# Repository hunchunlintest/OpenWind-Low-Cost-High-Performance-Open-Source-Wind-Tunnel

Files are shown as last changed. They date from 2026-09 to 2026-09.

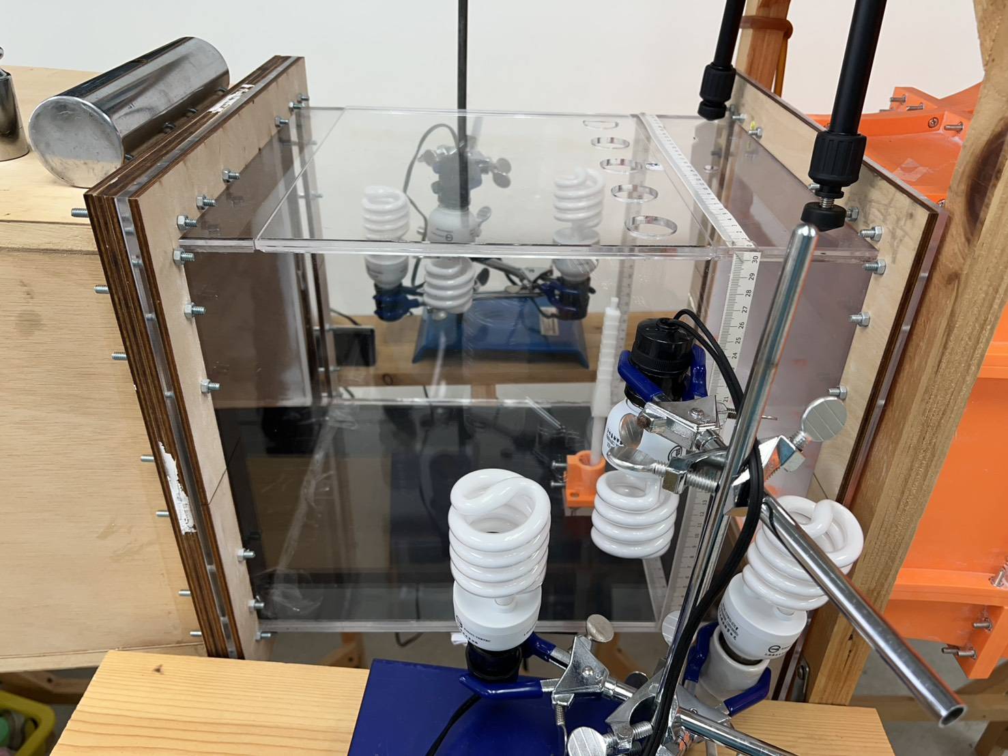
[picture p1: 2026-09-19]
Pictures/Test_Section.jpg

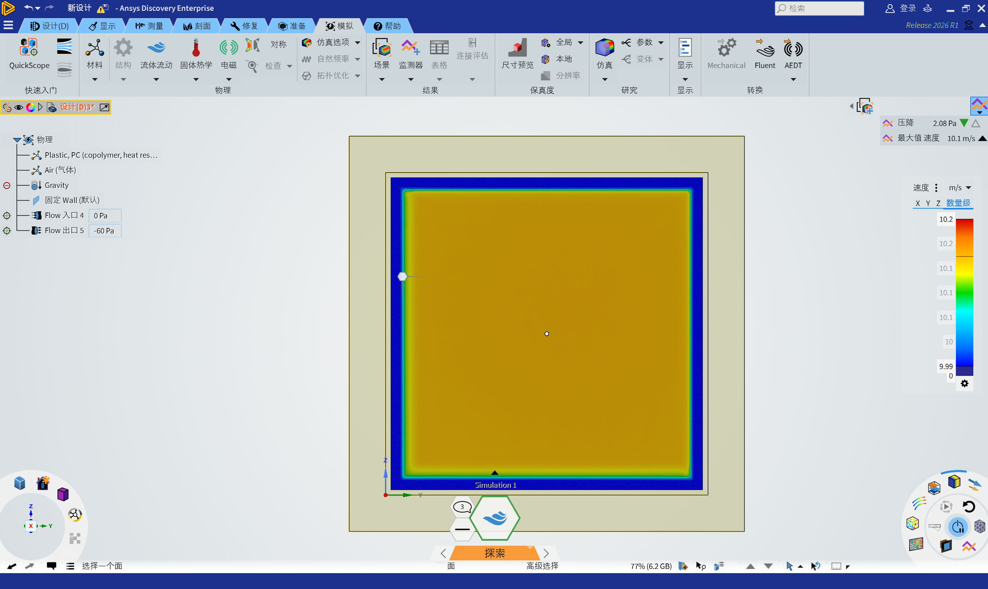
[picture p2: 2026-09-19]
Simulation/Boundary_Test_Section.png

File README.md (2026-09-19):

# OpenWind-Low-Cost-High-Performance-Open-Source-Wind-Tunnel
An open-source, suction-type continuous wind tunnel engineered for low cost and easy assembly. Features a 900 cm² test section, CAD files, Arduino control firmware, and assembly guides. Optimized via ANSYS Discovery to deliver precise PWM speed control (up to 10 m/s) with high flow uniformity and low turbulence (T.I. < 1.6%).

---

> ⚠️ **Important Notes:**
> * Ensure your room has sufficient space to accommodate the assembled wind tunnel structure and proper airflow!
> * You may need to modify the CAD models to fit your specific 3D printer dimensions or hardware components.
> * You will need to design a custom support frame based on your specific environment and perform system calibration prior to testing.
> * If you need help, please contact me. Email: edisonlin2009@proton.me

---

## 📂 Repository Structure (Directory Contents)

| Directory / File | Description |
| :--- | :--- |
| **`Contraction Cone/`** | Specifications and post-processing guide for the 3D-printed contraction section. |
| **`Diffuser Section/`** | Dimensions and setup for the wooden expansion duct for pressure recovery. |
| **`Gallery/`** | High-resolution photographs showcasing the physical assembly and individual modules. |
| **`Power Section/`** | Arduino PWM control firmware (`.ino`), wiring guidelines, and fan array setup. |
| **`Simulation/`** | ANSYS Discovery CFD analysis visualizations (velocity contours, streamlines). |
| **`Straightening Section/`** | DIY instructions for the drinking straw honeycomb array and wire mesh. |
| **`Test Section/`** | Specifications for the transparent acrylic observation area and sensor ports. |
| **`PRICE_LIST.md`** | Detailed itemized Bill of Materials (BOM) with estimated USD costs. |
| **`LICENSE`** | MIT License open-source legal information. |

---

## 🛠️ Hardware & Bill of Materials (BOM)

### 1. Wind Tunnel Structure Modules
*   **Flow Straightener Section (Honeycomb & Mesh)**:
    *   Plastic straws (1 cm diameter, aligned in a honeycomb pattern)
    *   Stainless steel wire mesh
*   **Contraction Section (Contraction Cone)**:
    *   3D printed components (PLA)
    *   Wall putty / spackle
*   **Test Section (Observation Section)**:
    *   Acrylic plates
    *   Pre-drilled ports for Pitot tube and smoke generator injection
*   **Diffuser Section**:
    *   Tapered enclosure panels (Length: 120 cm)

### 2. Power & Control System (You can choose your own!)
*   **Fans**: Snow Fan YY20060H24 × 4 
*   **Microcontroller**: Arduino UNO × 1
*   **Motor Driver**: APO-L3 PWM Controller × 1
*   **Power Supply**: MEAN WELL LRS-350-24 (24V) × 1

### 3. Optional Measurement & Testing Gear
*   Pitot tube anemometer (e.g., PASCO ME-2221)
*   Smoke generator (for flow visualization)
*   High-speed camera (e.g., XIMEA XIQ)

---

## 💻 Software & Files

*   **Autodesk Fusion 360**: 3D structural model source files (`.f3d`) and printable files (`.stl`).
*   **Arduino IDE**: Firmware for fan speed control via PWM (`.ino`).

---

## 📊 Performance Specs

Replicated and measured experimentally, this setup achieves the following specifications:

*   **Test Section Cross-Section**: 900 cm² (30 cm × 30 cm)
*   **Maximum Wind Speed**: 10 m/s
*   **Flow Field Uniformity**: Post-sanding treatment of the contraction cone reduces test section Turbulence Intensity (T.I.) to below **1.6%**.
*   **Control Linearity**: High linear relationship ($R^2 = 0.9996$) between Arduino PWM duty cycle and average test section wind speed.
*   **Operating Stability**: Continuous 60-minute test shows 5-minute average wind speed fluctuations staying within a **$\pm 5\%$** error margin.

---

## 🚀 Getting Started

1. **Download CAD Files**: Clone this repository and navigate to the CAD directory to get the `.stl` files.
2. **3D Printing & Post-Processing**: Print the contraction cone parts and assemble them. **Apply wall putty to the interior walls and sand repeatedly until smooth** to ensure low turbulence intensity.
3. **Assemble Main Structure**: Connect the components in sequence: Straightener $\rightarrow$ Contraction Cone $\rightarrow$ Acrylic Test Section $\rightarrow$ Diffuser $\rightarrow$ Fan Power Section. Seal all joining edges to prevent air leaks. Secure the entire assembly onto your custom-built support frame.
4. **Wiring & Firmware Flashing**:
   * Connect the Arduino UNO, APO-L3 PWM driver, LRS-350-24 power supply, and Snow Fans according to the provided circuit diagram.
   * Open Arduino IDE and upload the control script to the Arduino UNO.
5. **Operation & Calibration**: Power on the system, send PWM signals to control fan speed, and use your measurement tools (e.g., Pitot tube) to calibrate the wind speed against the PWM output for your specific build environment.

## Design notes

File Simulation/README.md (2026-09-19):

# 🌪️ Simulation & CFD Analysis

This directory contains Computational Fluid Dynamics (CFD) simulation results used to verify and optimize the aerodynamic performance of the OpenWind modular wind tunnel.
## 💻 Simulation Software
The modeling, simulation, and visualization were conducted using **ANSYS Discovery**, leveraging its rapid simulation capabilities to iterate on the contraction cone and diffuser designs.

## 📊 Key Results (Visualizations)
Below are two key visualization results from our ANSYS Discovery analysis.

<!-- IMPORTANT: Please rename the image filenames in this directory to match your actual uploaded file names and replace them in the paths below (e.g., replace './image_7.png' with './sim_full_streamlines.png'). -->

### 1. Wind Tunnel Flow Path Streamlines (Overview)

*   **Description**: This full wind tunnel overview displays flow path streamlines colored by velocity magnitude. It demonstrates:
    *   Efficient flow acceleration through the 3D-printed contraction cone.
    *   Smooth flow development into the test section, validating the overall modular design.
    *   Effective velocity recovery within the diffuser section before exhaust.
*   **Result**: The simulation indicates a smooth velocity increase from the straightener to the test section.

### 2. Test Section Velocity Contour (Cross-Section)

*   **Description**: This is a cross-sectional velocity contour plot taken directly from the acrylic test section. It is designed to verify:
    *   High flow uniformity across the 900 cm² (30 cm x 30 cm) working area.
    *   Minimal turbulence and low velocity boundary layers at the square edges.
*   **Result**: The core region shows excellent velocity uniformity, with a maximum velocity of approximately **$10.2\text{ m/s}$**, validating the design's ability to achieve the target maximum wind speed.

---

## 📁 Full Simulation Files Request

> **⚠️ Notice regarding raw files:**
> Due to GitHub's file size limitations, the original complete ANSYS Discovery simulation files (project databases, full result sets, and volumetric data) **exceed the 25MB upload limit** and are not hosted directly in this repository.

If you require the original simulation data for academic verification, joint research, or your own modifications, please feel free to contact me directly:

📧 **Email**: [edisonlin2009@proton.me](mailto:edisonlin2009@proton.me)

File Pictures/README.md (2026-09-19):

#Pictures

This gallery contains high-resolution photographs showcasing the physical assembly, structural components, measurement setup, and power system of the OpenWind modular wind tunnel.

---

## 🖼️ Modular Overview & Components

| Image | Component / Module | Description |
| :---: | :--- | :--- |
| **`Full_Windtunnel.jpg`** | **Full Assembly ** | Side view of the complete open-source modular wind tunnel system mounted on a wooden framework, showing the flow progression from intake to exhaust. |
| **`Straighten_Section.jpg`** | **Straightening Section ** | Front view of the intake module featuring the wooden casing, $10\text{ mm}$ drinking straw honeycomb array, fine wire mesh screen, and pressure sensing probe. |
| **`Convergent_Section.jpg`** | **Contraction Cone ** | Side profile of the 3D-printed orange contraction cone designed to accelerate air into the test section while minimizing turbulence. |
| **`Test_Section.jpg`** | **Test Section ** | Transparent acrylic working section equipped with lighting fixtures, measurement rulers, and test model mounting rigs. |
| **`Diffusion_Section.jpg`** | **Diffuser Section ** | Heavy-duty wooden expansion duct ($120\text{ cm}$ length, $2\text{ cm}$ wall thickness) designed for pressure recovery downstream of the test section. |
| **`Power_Section.jpg`** | **Power Section & Control ** | Rear exhaust module housing the $2 \times 2$ array of $20\text{ cm} \times 20\text{ cm}$ fans, connected to the PWM microcontroller control setup and data acquisition workstation. |

---

## 🛠️ Usage in Documentation

You can reference these images in your respective sub-module `README.md` files using standard Markdown syntax:

```markdown
![Straightening Section](./Straighten_Section.jpg)

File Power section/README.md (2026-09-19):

# Power Section

This directory contains the specification, wiring guidelines, and safety instructions for the Power Section of the open-source wind tunnel.

The power section serves as the primary suction power source, drawing air through the entire tunnel system using a multi-fan array with integrated power supply and PWM speed control electronics.

---

## 📂 Directory Contents

| File Name | Format | Description |
| :--- | :---: | :--- |
| **`Power_Section.ino`** | Arduino (`.ino`) | Embedded C++ sample code for microcontroller PWM fan speed control, timer setup, and dynamic duty cycle mapping. |

---

## 📐 Hardware Specifications & Configuration

* **Fan Matrix**: $2 \times 2$ grid array (Total of 4 high-performance exhaust fans)
* **Fan Frame Dimensions**: $20\text{ cm} \times 20\text{ cm}$ per fan (Total cross-section area fits the outlet of the diffuser)
* **Drive Type**: Pull-through (suction) configuration mounted at the downstream exit of the diffuser
* **Operating Voltage**: 12V / 24V DC (depending on selected fan model)

---

## ⚡ Electrical & Control System

The electrical system consists of three core components: Power Supply Unit (PSU), Speed Controller, and Safety Circuitry.

### 1. Power Supply Unit (PSU)
* **Voltage Rating**: Matches fan requirements (typically 12V or 24V DC).
* **Current Capacity**: Ensure the PSU rated current ($A$) exceeds the total combined peak current draw of all 4 fans by at least **20–30%** (Safety Margin).

### 2. Speed Control (PWM)
* **Control Signal**: 4-wire PWM (Pulse Width Modulation) signal generator or microcontroller (e.g., Arduino / ESP32) for precise wind speed tuning.
* **Synchronization**: All 4 fans must receive identical PWM signal duty cycles to maintain uniform suction pressure across the exit boundary.

### 3. Wiring Guidelines
* **Bus Wiring**: Wire power in parallel across all 4 fans using appropriate gauge wire (e.g., 16–18 AWG) to prevent voltage drops.
* **Common Ground**: Ensure a common ground (GND) is shared between the PWM controller and the main power supply.

---

## 🛠️ Assembly & Safety Guidelines

1. **Vibration Isolation**:
   * Mount rubber gaskets or silicone dampeners between the fan housing and the diffuser mounting flange to minimize structural vibration and resonance.
2. **Safety Grilles / Finger Guards**:
   * **Mandatory**: Install protective wire mesh or fan guards on the rear exhaust face to prevent accidental contact with spinning blades.
3. **Thermal Management**:
   * Enclose all control electronics and terminal blocks inside a ventilated, flame-retardant junction box.

---

## ✏️ Customization & Modifications

> ⚠️ **Important Note:** You can adapt this power section for different fan dimensions or higher-voltage brushless motors (EDF) by adjusting the power supply capacity and speed controller specifications accordingly.

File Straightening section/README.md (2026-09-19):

# Straightening Section

This directory contains the CAD models, manufacturing specs, and assembly instructions for the Straightening Section located at the wind tunnel inlet.

The straightening section stabilizes incoming ambient air by eliminating large-scale eddies, swirl, and non-uniform lateral velocities before the air enters the contraction cone.

Notice: The CAD in this File is without the pipes.

---

## 📐 Dimensional Specifications

* **Outer Frame Cross-Section**: $60\text{ cm} \times 60\text{ cm}$ (Matches the inlet opening of the contraction cone)
* **Honeycomb Cell Diameter**: $10\text{ mm}$ (Array constructed using densely packed drinking straws)
* **Honeycomb Depth**: $13\text{ cm}$
* **Damping Mesh / Screen**: Fine stainless steel wire mesh placed upstream and downstream of the straw honeycomb block
* **Outer Frame Material**: Custom wooden enclosure framing

---

## 📂 Directory Contents

| File Name | Format | Description |
| :--- | :---: | :--- |
| **`Straightening_Section.pdf`** | PDF | Technical engineering drawing showing dimensions of the wooden frame layout. |
| **`Straightening_Section.step`** | STEP (`.step`) | 3D CAD model of the outer wooden housing and assembly structure. |

---

## 🛠️ Material & DIY Manufacturing Guidelines

The straightening section is constructed using accessible low-cost materials:

1. **Wooden Outer Frame**:
   * Build a robust $60\text{ cm} \times 60\text{ cm}$ inner-dimension box (with a depth of at least $13\text{ cm}$) using wooden panels to serve as the structural casing.
2. **Drinking Straw Honeycomb Core**:
   * **Material**: Standard plastic drinking straws ($10\text{ mm}$ diameter, cut to $13\text{ cm}$ lengths).
   * **Assembly**: Bundle and align straws tightly in a parallel hexagonal pattern inside the wooden frame until the entire $60\text{ cm} \times 60\text{ cm}$ cross-section is completely filled. Secure the bundle edges with spray adhesive or side clamping panels.
3. **Stainless Steel Screen Mesh**:
   * Fasten fine stainless steel wire mesh onto both the front (intake) and rear (outlet) faces of the wooden frame to secure the straw matrix and further reduce flow fluctuations.

---

## ✏️ Customization & Modifications

> ⚠️ **Important Note:** You can adjust the wooden panel thickness or overall frame depth to match alternative straw lengths or custom mounting flanges on the downstream contraction cone.

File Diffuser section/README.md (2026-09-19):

# Diffuser Section
This directory contains the CAD models, dimensional specifications, and assembly instructions for the Diffuser Section of the open-source wind tunnel.

The diffuser is a tapered expansion duct designed to gradually decelerate high-velocity airflow exiting the test section, reducing static pressure losses and preventing downstream wake instability.

---

## 📐 Dimensional Specifications

* **Total Length**: $120\text{ cm}$
* **Inlet Cross-Section**: $30\text{ cm} \times 30\text{ cm}$ (Matches the acrylic test section output)
* **Outlet Cross-Section**: Tapered expansion to fit the fan drive array housing
* **Wall Thickness**: $2\text{ cm}$ ($20\text{ mm}$) board/panel material construction
* **Duct Profile**: Linear geometric expansion optimized for stable pressure recovery

---

## 📂 Directory Contents

| File Name | Format | Description |
| :--- | :---: | :--- |
| **`擴散器部分.pdf`** | PDF | Engineering technical drawing detailing overall dimensions. |
| **`擴散器部分.步驟`** | STEP (`.step`) | Standard 3D CAD exchange file for CAD editing software import. |

---

## 🛠️ Fabrication & Assembly Guidelines

Depending on your available tools and workspace, the 120 cm long diffuser can be built using sheet materials or 3D printed modular sections:

1. **Sheet Material Construction (Recommended)**:
   * **Materials**: $2\text{ cm}$ thick wood/MDF boards, acrylic panels, or dense plastic sheets.
   * **Cutting**: Cut 4 trapezoidal panels (taking the $2\text{ cm}$ material thickness into account for edge overlaps).
2. **Air Tightness (Critical)**:
   * Apply silicone sealant or foam gasket tape along all internal longitudinal seams.
   * Air leaks in the diffuser section degrade fan suction efficiency and introduce flow turbulence.
3. **Fan Array Attachment**:
   * Mount the 4× Snow Fan array securely at the outlet flange. Ensure vibration-dampening rubber pads are placed between the diffuser housing and fan frame.

---

## ✏️ Customization & Modifications

> ⚠️ **Important Note:** If you are using different fan models, alternative board thicknesses, or a custom power array, you may need to adjust the outlet cross-section dimensions and panel edge joint geometries in the CAD source file (`.f3d`) prior to fabrication.

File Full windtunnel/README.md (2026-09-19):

# Full Wind Tunnel

This directory contains the complete assembly CAD models, render images, and overall dimensional drawings for the entire open-source wind tunnel system.

It is designed to give users a clear high-level view of the full structure, component layout, and physical space requirements before manufacturing and assembly.

##Some of the Detail is not in the CAD in this File!

---

## 📐 Overall Dimensions & Workspace Requirements

Please review these overall spatial specs to ensure your workspace or lab environment can accommodate the fully assembled unit:

* **Total Length**: Approx. $2.5\text{ m} - 3.0\text{ m}$ (including Honeycomb, Contraction Cone, Test Section, Diffuser, and Fan Array).
* **Cross-Sectional Height & Width**: Max outer dimension approx. $60\text{ cm} \times 60\text{ cm}$ at the contraction/diffuser ends.
* **Test Section Working Area**: $30\text{ cm} \times 30\text{ cm} \times 40\text{ cm}$.

> ⚠️ **Workspace Clearance Notice:** Ensure a minimum clearance of **1 meter** around both the front air intake (honeycomb) and the rear exhaust (fans) to prevent flow restriction or wall interference.

---

## 🛠️ Assembly Sequence Overview

The wind tunnel modules should be connected in the following order along the flow path:

1. **Honeycomb / Flow Straightener** (Inlet)
2. **Contraction Cone** (Flow Acceleration)
3. **Acrylic Test Section** (Observation & Measurement)
4. **Diffuser** (Flow Expansion)
5. **Fan Drive Array & Housing** (Power & Exhaust)

---

## ✏️ Customization & Adjustments

> ⚠️ **Important Note:** You can open the source assembly file in Autodesk Fusion 360 to measure specific clearance dimensions, export custom sections, or modify adapter flanges to fit alternative components.

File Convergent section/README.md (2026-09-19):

# Contraction Section

This directory contains the CAD models, 3D printing files, and post-processing instructions for the contraction cone section of the open-source wind tunnel.

The contraction cone is a critical component designed to accelerate incoming airflow and significantly improve flow uniformity while minimizing turbulence intensity before entering the test section.

---

## 📂 Directory Contents & 3D Printing Quantities

The contraction cone is split into 8 different zones and sub-blocks to fit standard desktop 3D printer build volumes. 

> ⚠️ **Note on File Naming:** The number in parentheses `(xN)` inside the filename indicates the **required quantity to print** for that specific component.

| File Name | Required Quantity | Description |
| :--- | :---: | :--- |
| **`WINDZONE1-1(x4).stl`** | 4 | Contraction Cone Zone 1 - Part 1 |
| **`WINDZONE1-2(x8).stl`** | 8 | Contraction Cone Zone 1 - Part 2 |
| **`WINDZONE2-1(x4).stl`** | 4 | Contraction Cone Zone 2 - Part 1 |
| **`WINDZONE2-2(x8).stl`** | 8 | Contraction Cone Zone 2 - Part 2 |
| **`WINDZONE3-1(x4).stl`** | 4 | Contraction Cone Zone 3 - Part 1 |
| **`WINDZONE3-2(x4).stl`** | 4 | Contraction Cone Zone 3 - Part 2 |
| **`WINDZONE4-1(x4).stl`** | 4 | Contraction Cone Zone 4 - Part 1 |
| **`WINDZONE4-2(x4).stl`** | 4 | Contraction Cone Zone 4 - Part 2 |

* **Total Printed Parts**: 40 individual pieces.

---

## 🛠️ Manufacturing & Post-Processing (Crucial Step)

The interior surface quality of the contraction cone directly impacts the turbulence intensity (T.I.) in the test section. To achieve a T.I. below **1.6%**, follow these post-processing steps:

1. **3D Printing**:
   * **Material**: PLA (or ABS/PETG).
   * **Infill**: 15–20% is sufficient.
     
2. **Assembly**:
   * Assemble the printed sub-blocks using M8 screw.
   * Ensure structural alignment along the interior contraction profile.
     
3. **Surface Smoothing (Required)**:
   * **Spackle / Wall Putty**: Apply wall putty or filler evenly across all interior seams and layer lines.
   * **Sanding**: Repeatedly sand the interior surface using progressively finer sandpaper (e.g., 200 $\rightarrow$ 400 $\rightarrow$ 800 grit) until completely smooth.
   * **Finishing**: Apply a coat of primer or clear spray paint to seal the surface.

---

## ✏️ Customization & Modifications

> ⚠️ **Important Note:** Depending on your 3D printer's build volume or specific structural needs, you may need to modify the CAD models to adjust the section splitting or wall thickness before printing.

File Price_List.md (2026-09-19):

# 🏷️ Price List & Cost Breakdown

> ⚠️ **Disclaimer
> The prices listed below are **rough estimates** based on average online pricing for standard materials. **Actual costs will vary depending on your local material prices, shipping fees, inflation, and any additional manufacturing/processing costs** (e.g., custom laser cutting for acrylic or professional 3D printing services if not done in-house).

This document provides a detailed estimation of the material costs required to build the OpenWind modular wind tunnel in USD.

## 🛒 Estimated Cost Table

| Module | Item | Specifications | Qty | Unit Price (USD) | Total (USD) |
| :--- | :--- | :--- | :---: | :---: | :---: |
| **General** | Wooden Panels | 2 cm thickness (for Diffuser & Frames) | 1 set | $45.00 | $45.00 |
| **General** | Fasteners | M4/M5 screws, metal L-brackets | 1 set | $10.00 | $10.00 |
| **Straightening** | Drinking Straws | 10 mm diameter, bulk (cut to 13 cm) | 1 set | $20.00 | $20.00 |
| **Straightening** | Wire Mesh | Fine stainless steel mesh (60 x 60 cm) | 2 pcs | $8.00 | $16.00 |
| **Contraction** | 3D Filament | PLA or PETG (approx. 2-3 spools) | 3 kg | $18.00 | $54.00 |
| **Test Section** | Clear Acrylic | 30 x 30 x 40 cm working area | 1 set | $35.00 | $35.00 |
| **Power Section** | Exhaust Fans | 20 x 20 cm, 12V or 24V DC | 4 pcs | $22.00 | $88.00 |
| **Power Section** | Power Supply (PSU)| Matched to fans (20-30% safety margin)| 1 set | $35.00 | $35.00 |
| **Power Section** | Microcontroller | Arduino Uno / Nano or ESP32 | 1 pc | $8.00 | $8.00 |
| **Power Section** | Electronics | 10k Potentiometer, 16-18 AWG wires | 1 set | $5.00 | $5.00 |
| **Power Section** | Fan Guards | 20 x 20 cm metal safety grills | 4 pcs | $3.50 | $14.00 |
| **Total Estimation**| | | | | **~$330.00** |

---

## 💡 Cost Optimization Notes

* **Cost-Efficiency**: Traditional commercial wind tunnels can cost thousands to tens of thousands of dollars. By utilizing open-source 3D printed components, a DIY drinking straw honeycomb array, and standard industrial computer fans, the overall hardware cost of this project is successfully compressed to under **$350 USD**.
* **Price Variation & Processing**: As mentioned above, actual costs will heavily depend on regional availability. If you require third-party processing (such as CNC machining for wood panels or laser cutting for the acrylic test section), please factor those service fees into your budget.
* **Alternative Materials**: Builders can further reduce costs by using repurposed wood, recycled acrylic sheets, or salvaging power supplies from old desktop computers, depending on local resources.

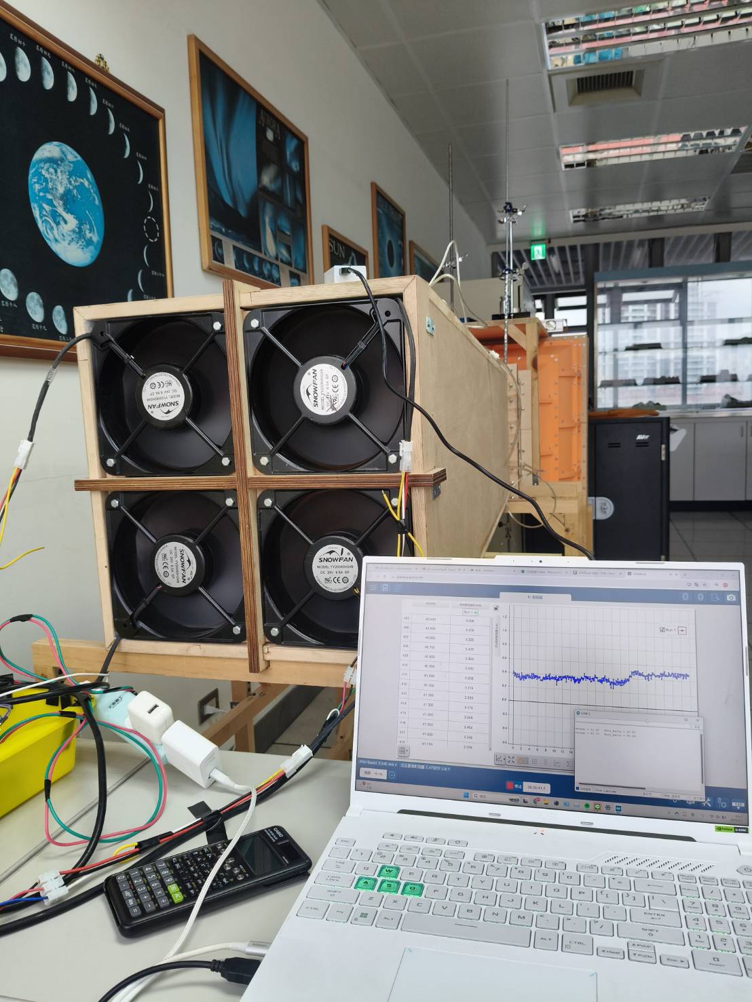
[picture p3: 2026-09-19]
Pictures/Power_Section.jpg

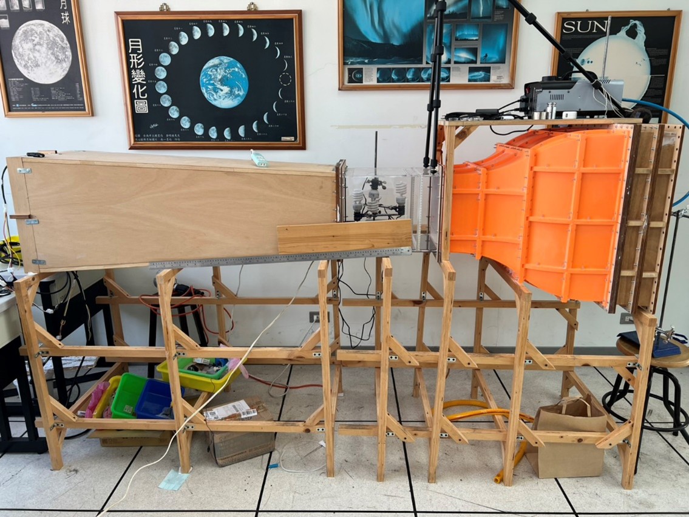
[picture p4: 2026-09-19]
Pictures/Full_Windtunnel.jpg

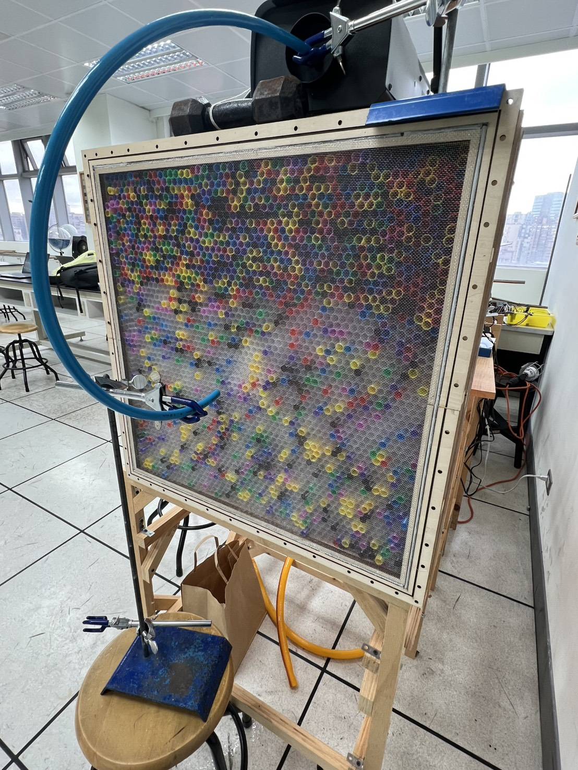
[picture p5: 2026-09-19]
Pictures/Straighten_Section.jpg

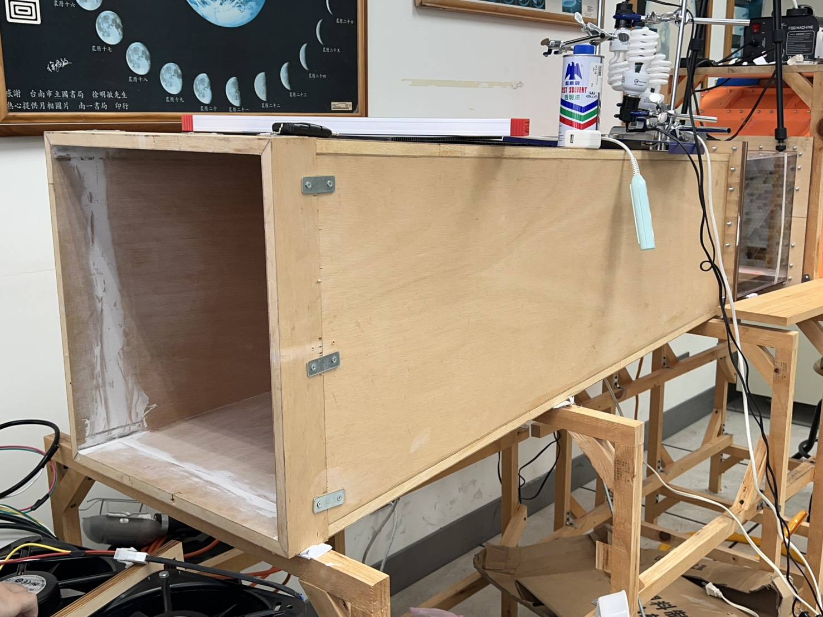
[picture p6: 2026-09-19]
Pictures/Diffusion_Section.jpg

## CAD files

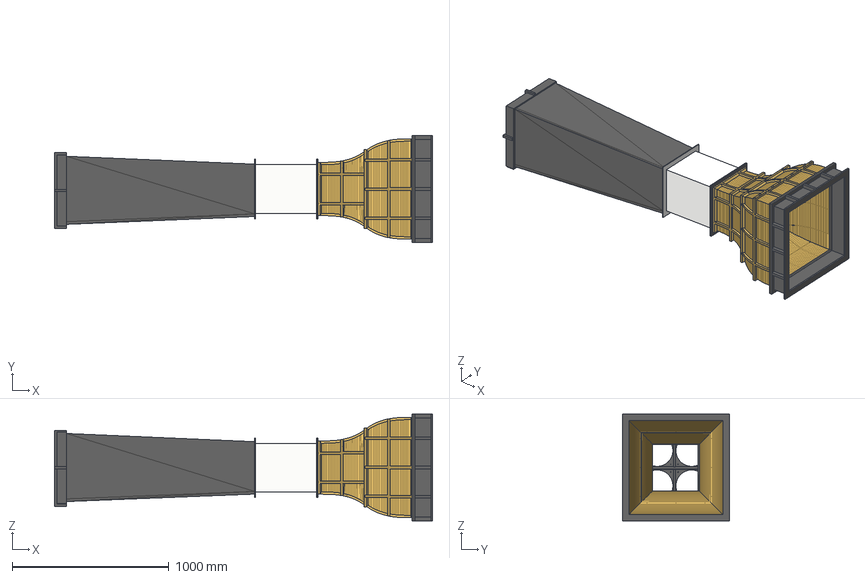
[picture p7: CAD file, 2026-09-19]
Full windtunnel/Full_Windtunnel.step
2410.2 x 680.0 x 680.0 mm
OuterShell x 4
TEST SECTION

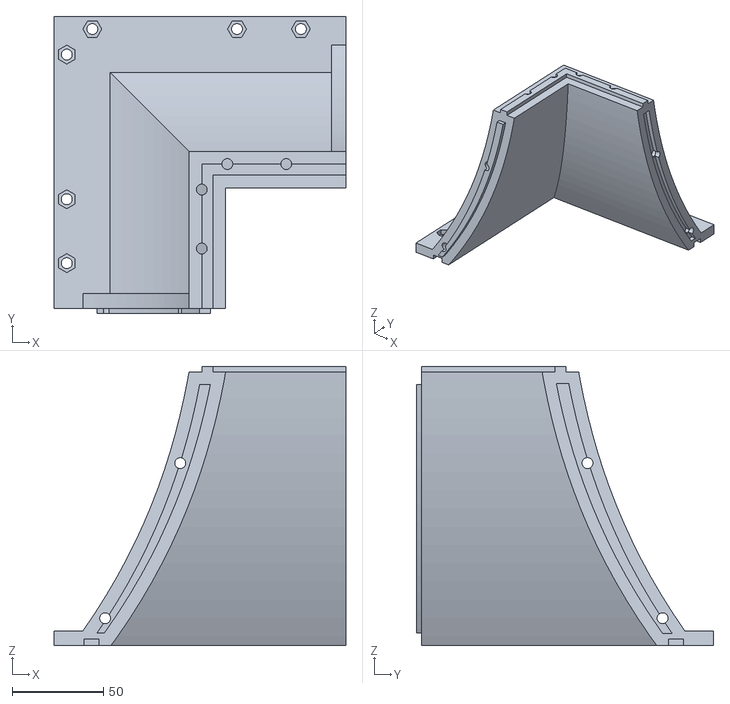
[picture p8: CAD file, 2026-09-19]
Convergent section/WINDZONE3-1(x4).stl
160.0 x 163.0 x 153.0

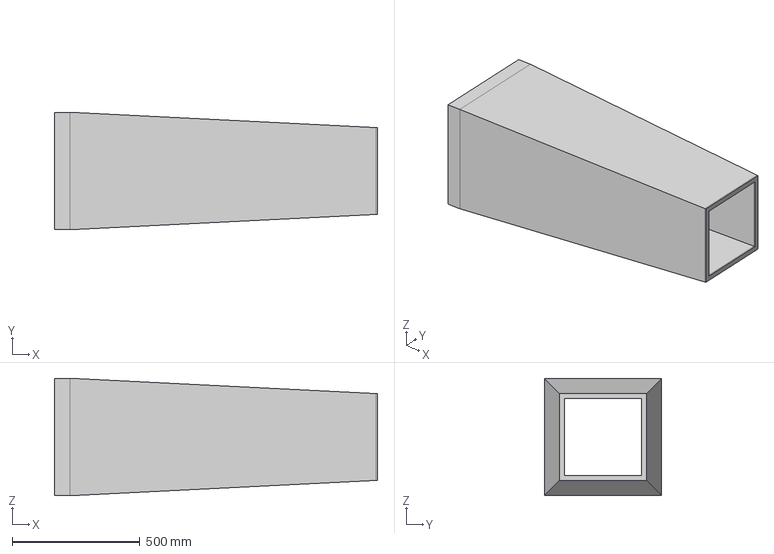
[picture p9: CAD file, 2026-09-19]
Diffuser section/Diffuser_Section.step
1265.0 x 460.0 x 460.0 mm

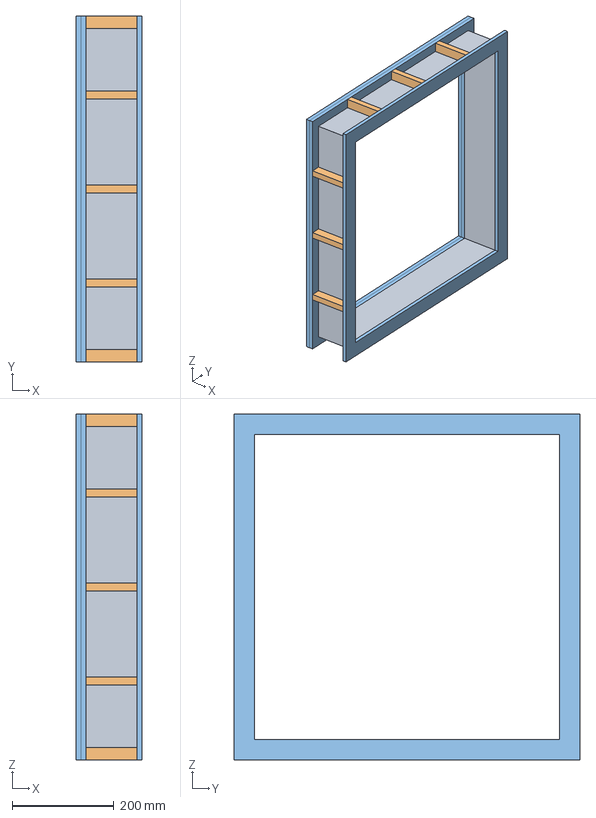
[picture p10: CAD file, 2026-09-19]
Straightening section/Straightening_Section.step
130.0 x 680.0 x 680.0 mm

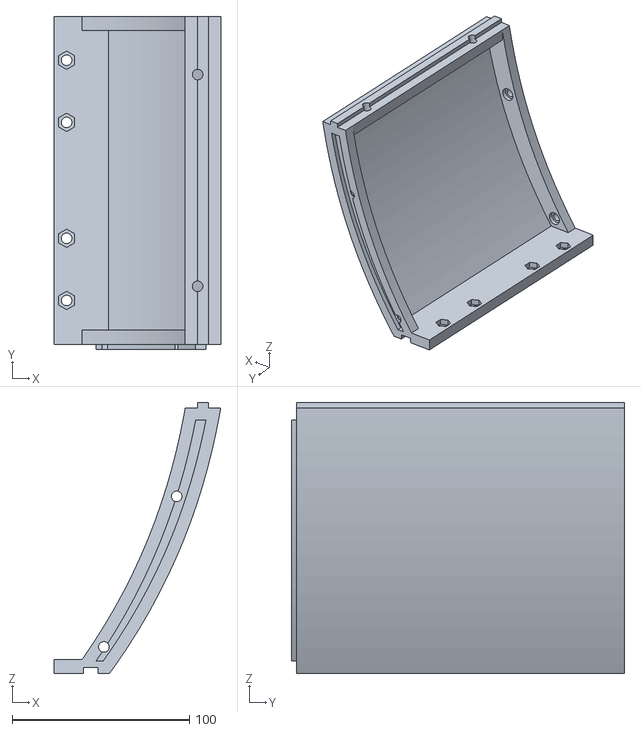
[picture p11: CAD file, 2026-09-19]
Convergent section/WINDZONE3-2(x4).stl
94.1 x 188.1 x 153.0

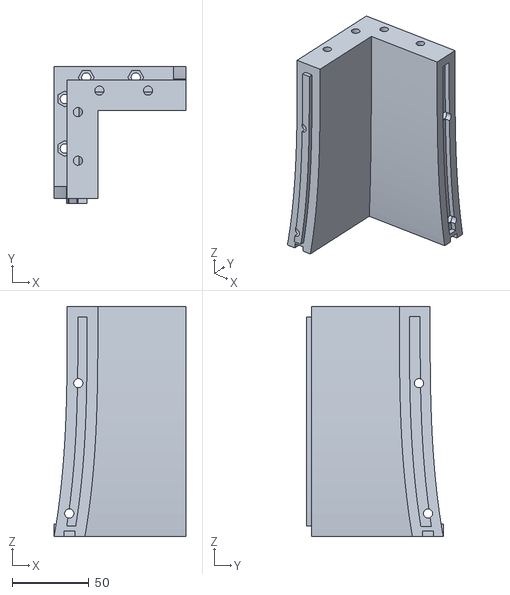
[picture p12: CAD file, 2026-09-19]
Convergent section/WINDZONE4-1(x4).stl
86.0 x 89.0 x 150.0

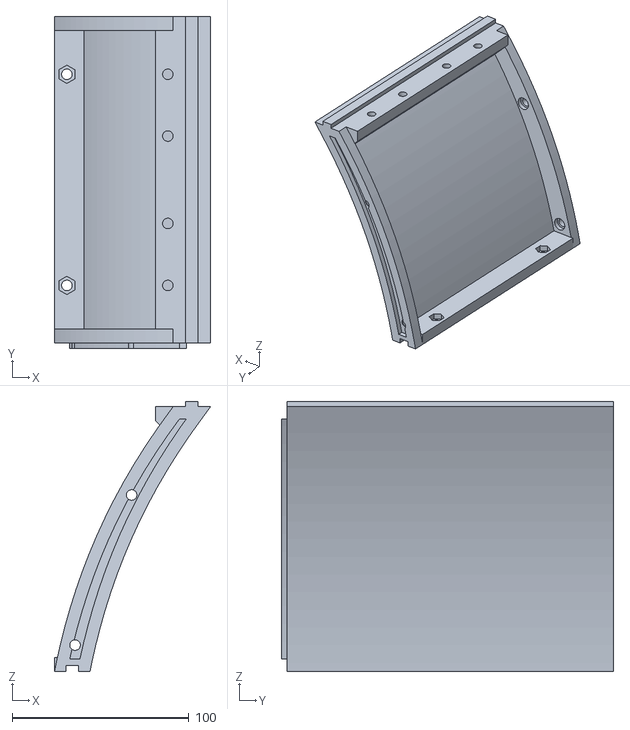
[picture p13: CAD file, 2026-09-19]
Convergent section/WINDZONE2-2(x8).stl
88.4 x 188.0 x 153.0

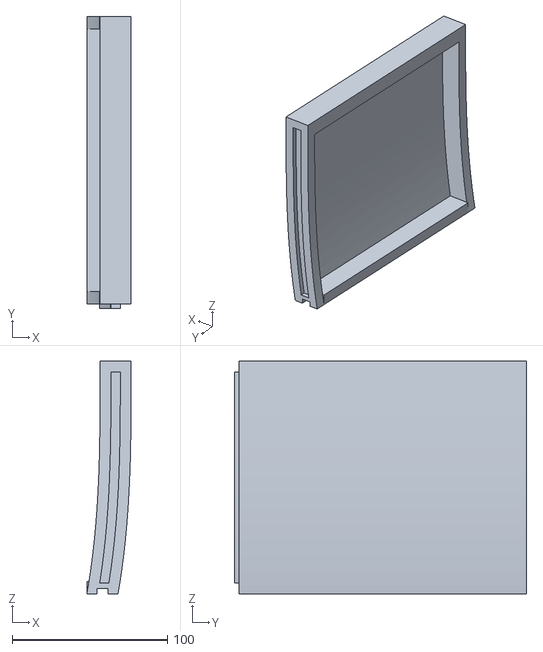
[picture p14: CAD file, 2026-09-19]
Convergent section/WINDZONE4-2(x4).stl
28.6 x 188.1 x 150.0

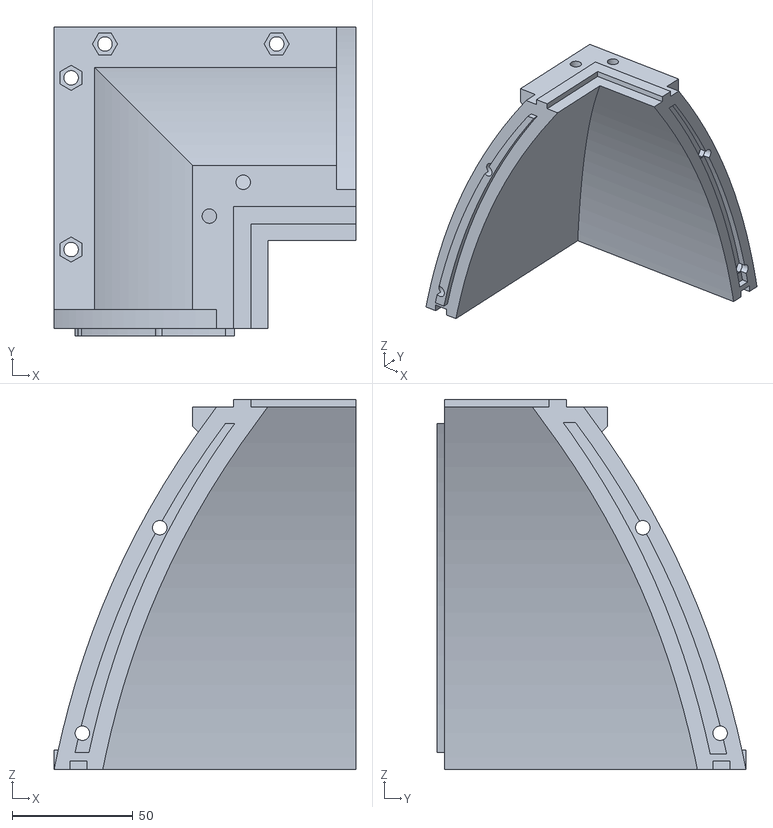
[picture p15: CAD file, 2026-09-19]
Convergent section/WINDZONE2-1(x4).stl
124.7 x 127.7 x 153.0

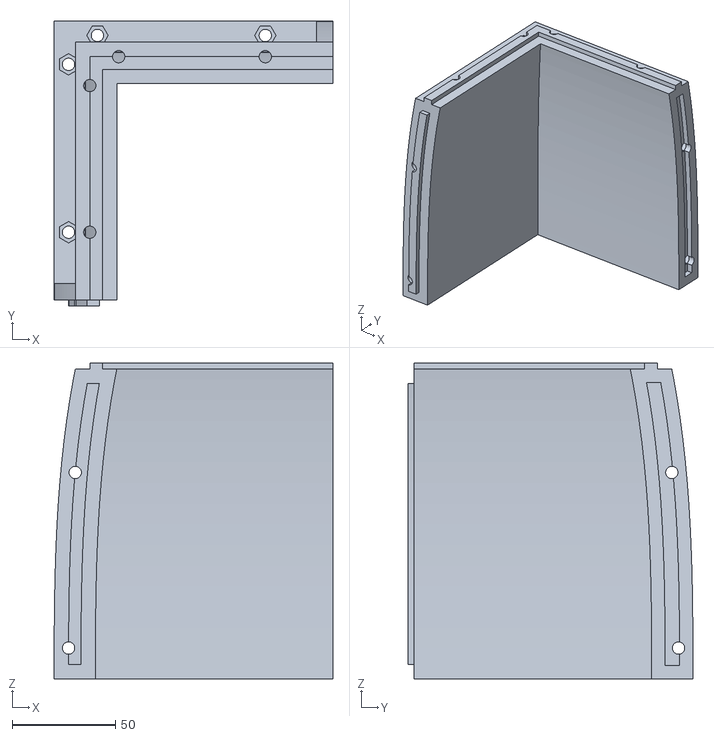
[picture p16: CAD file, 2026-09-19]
Convergent section/WINDZONE1-1(x4).stl
135.0 x 138.0 x 153.0

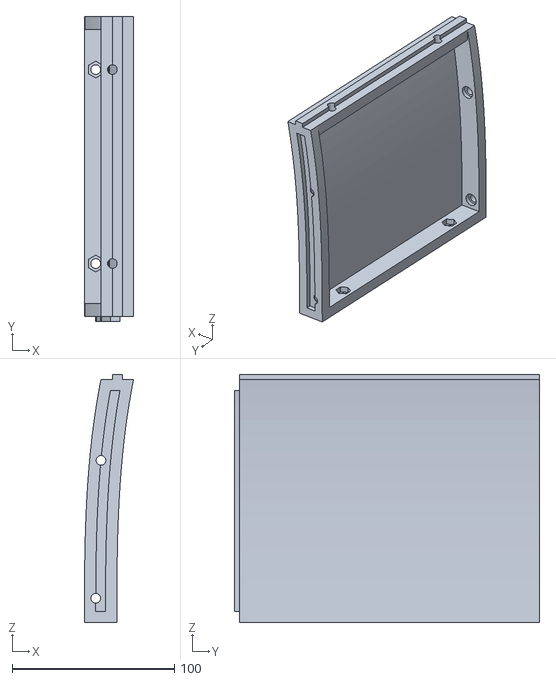
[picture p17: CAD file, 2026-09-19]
Convergent section/WINDZONE1-2(x8).stl
30.4 x 188.0 x 153.0

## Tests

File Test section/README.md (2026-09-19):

# Test Section

This directory contains the engineering technical drawings for the acrylic Test Section of the open-source wind tunnel. 

The test section provides a clear, highly transparent chamber for optical flow visualization (e.g., smoke streams) and sensor probe measurements (e.g., Pitot tubes).

---

## 📂 Directory Contents

* **`Test_Section_Drawing.pdf`** : Full engineering technical drawing detailing dimensional tolerances, plate thicknesses, and hole layouts.

---

## 📐 Dimensional Specifications

All dimensions in the drawing are in **centimeters (cm)**:

* **Internal Flow Cross-Section**: $30\text{ cm} \times 30\text{ cm}$ ($900\text{ cm}^2$ working area).
* **Total Chamber Length**: $40\text{ cm}$.
* **Outer Flange / Frame Dimensions**: $38\text{ cm} \times 38\text{ cm}$ (includes pre-drilled mounting bolt patterns).
* **Plate Thickness**: $0.5\text{ cm}$ ($5\text{ mm}$) transparent acrylic panel construction.
* **Top Measurement Ports**: 5 aligned circular ports spaced $6\text{ cm}$ apart along the centerline, designed for Pitot tube insertion, sensors, or smoke injection lines.

---

## 🛠️ Fabrication & Assembly Notes

1. **Material Recommendation**: 
   * Use high-transparency **acrylic (PMMA) sheets** ($0.5\text{ cm}$ / $5\text{ mm}$ thickness) for optimal optical visibility during camera recording.
2. **Manufacturing**:
   * Acrylic plates can be custom laser-cut using the provided engineering dimensions.
   * Ensure top hatch / cover plate allows easy access to swap experimental models or clean interior walls.
3. **Air Tightness**:
   * Seal all fixed joint edges with clear acrylic cement/glue or silicone strip gaskets to prevent pressure leaks that disrupt flow field measurement.

---

## ✏️ Customization & Modifications

> ⚠️ **Important Note:** You may modify the hole diameter, port spacing, or mounting flange locations according to your specific sensors (e.g., hot-wire anemometers, load cells) or custom mounting hardware.

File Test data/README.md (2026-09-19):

#  Core Test Data

This document details the simulation, fabrication, and core experimental data for the wind tunnel, including long-term stability, wind speed linearity, turbulence intensity, and Kármán vortex street observations.

---

## 1. Long-Term Stability Test (60-Minute Continuous Operation)

**Test Conditions:**
* Fan Duty Cycle: Fixed at `50%`
* Sampling Interval: Average wind speed and standard deviation recorded every 5 minutes

| Interval (min) | Avg Speed (m/s) | Std Dev (m/s) | Interval (min) | Avg Speed (m/s) | Std Dev (m/s) |
| :---: | :---: | :---: | :---: | :---: | :---: |
| **1–5** | 6.105 | 0.091 | **31–35** | 6.083 | 0.092 |
| **6–10** | 6.097 | 0.098 | **36–40** | 6.147 | 0.098 |
| **11–15** | 6.018 | 0.096 | **41–45** | 6.289 | 0.093 |
| **16–20** | 6.003 | 0.094 | **46–50** | 6.350 | 0.096 |
| **21–25** | 6.010 | 0.094 | **51–55** | 6.409 | 0.090 |
| **26–30** | 6.034 | 0.095 | **56–60** | 6.475 | 0.094 |

> **💡 Summary of Results:**
> Over the 60-minute test period, the average wind speed fluctuations per 5-minute interval remained strictly within an allowable error margin of **±5%**, demonstrating excellent operational stability during prolonged use.

---

## 2. Duty Cycle vs. Wind Speed in Central Test Area (3,3)

**Test Conditions:**
* Measurement Location: Center block `(3,3)` of the test section
* Duty Cycle Range: `20%` to `80%`
* Linear Regression: Strong linear correlation with $R^2 = 0.9996$

| Duty Cycle (%) | Avg Wind Speed (m/s) | Std Dev (m/s) |
| :---: | :---: | :---: |
| **20** | 2.3760 | 0.2048 |
| **25** | 2.9018 | 0.1824 |
| **30** | 3.5640 | 0.1620 |
| **35** | 4.2861 | 0.1338 |
| **40** | 4.8999 | 0.1027 |
| **45** | 5.4855 | 0.0965 |
| **50** | 6.1010 | 0.0935 |
| **55** | 6.7936 | 0.0832 |
| **60** | 7.4169 | 0.0727 |
| **65** | 7.9449 | 0.0642 |
| **70** | 8.5687 | 0.0597 |
| **75** | 9.2096 | 0.0639 |
| **80** | 9.8174 | 0.0640 |

---

## 3. Flow Field Uniformity

* **Before Sanding:** Prior to polishing the contraction section, turbulence intensity across test areas was within `2%`.
* **After Sanding:** Repeated applying of wall putty and fine sanding reduced turbulence intensity across all test areas to **below `1.6%`**, significantly improving flow uniformity.

## 4. Future Updates & Roadmap

* [ ] Full 3D spatial velocity mapping across all test section grids.
* [ ] Expanded dataset and complete test reports will be complemented in the next official release.

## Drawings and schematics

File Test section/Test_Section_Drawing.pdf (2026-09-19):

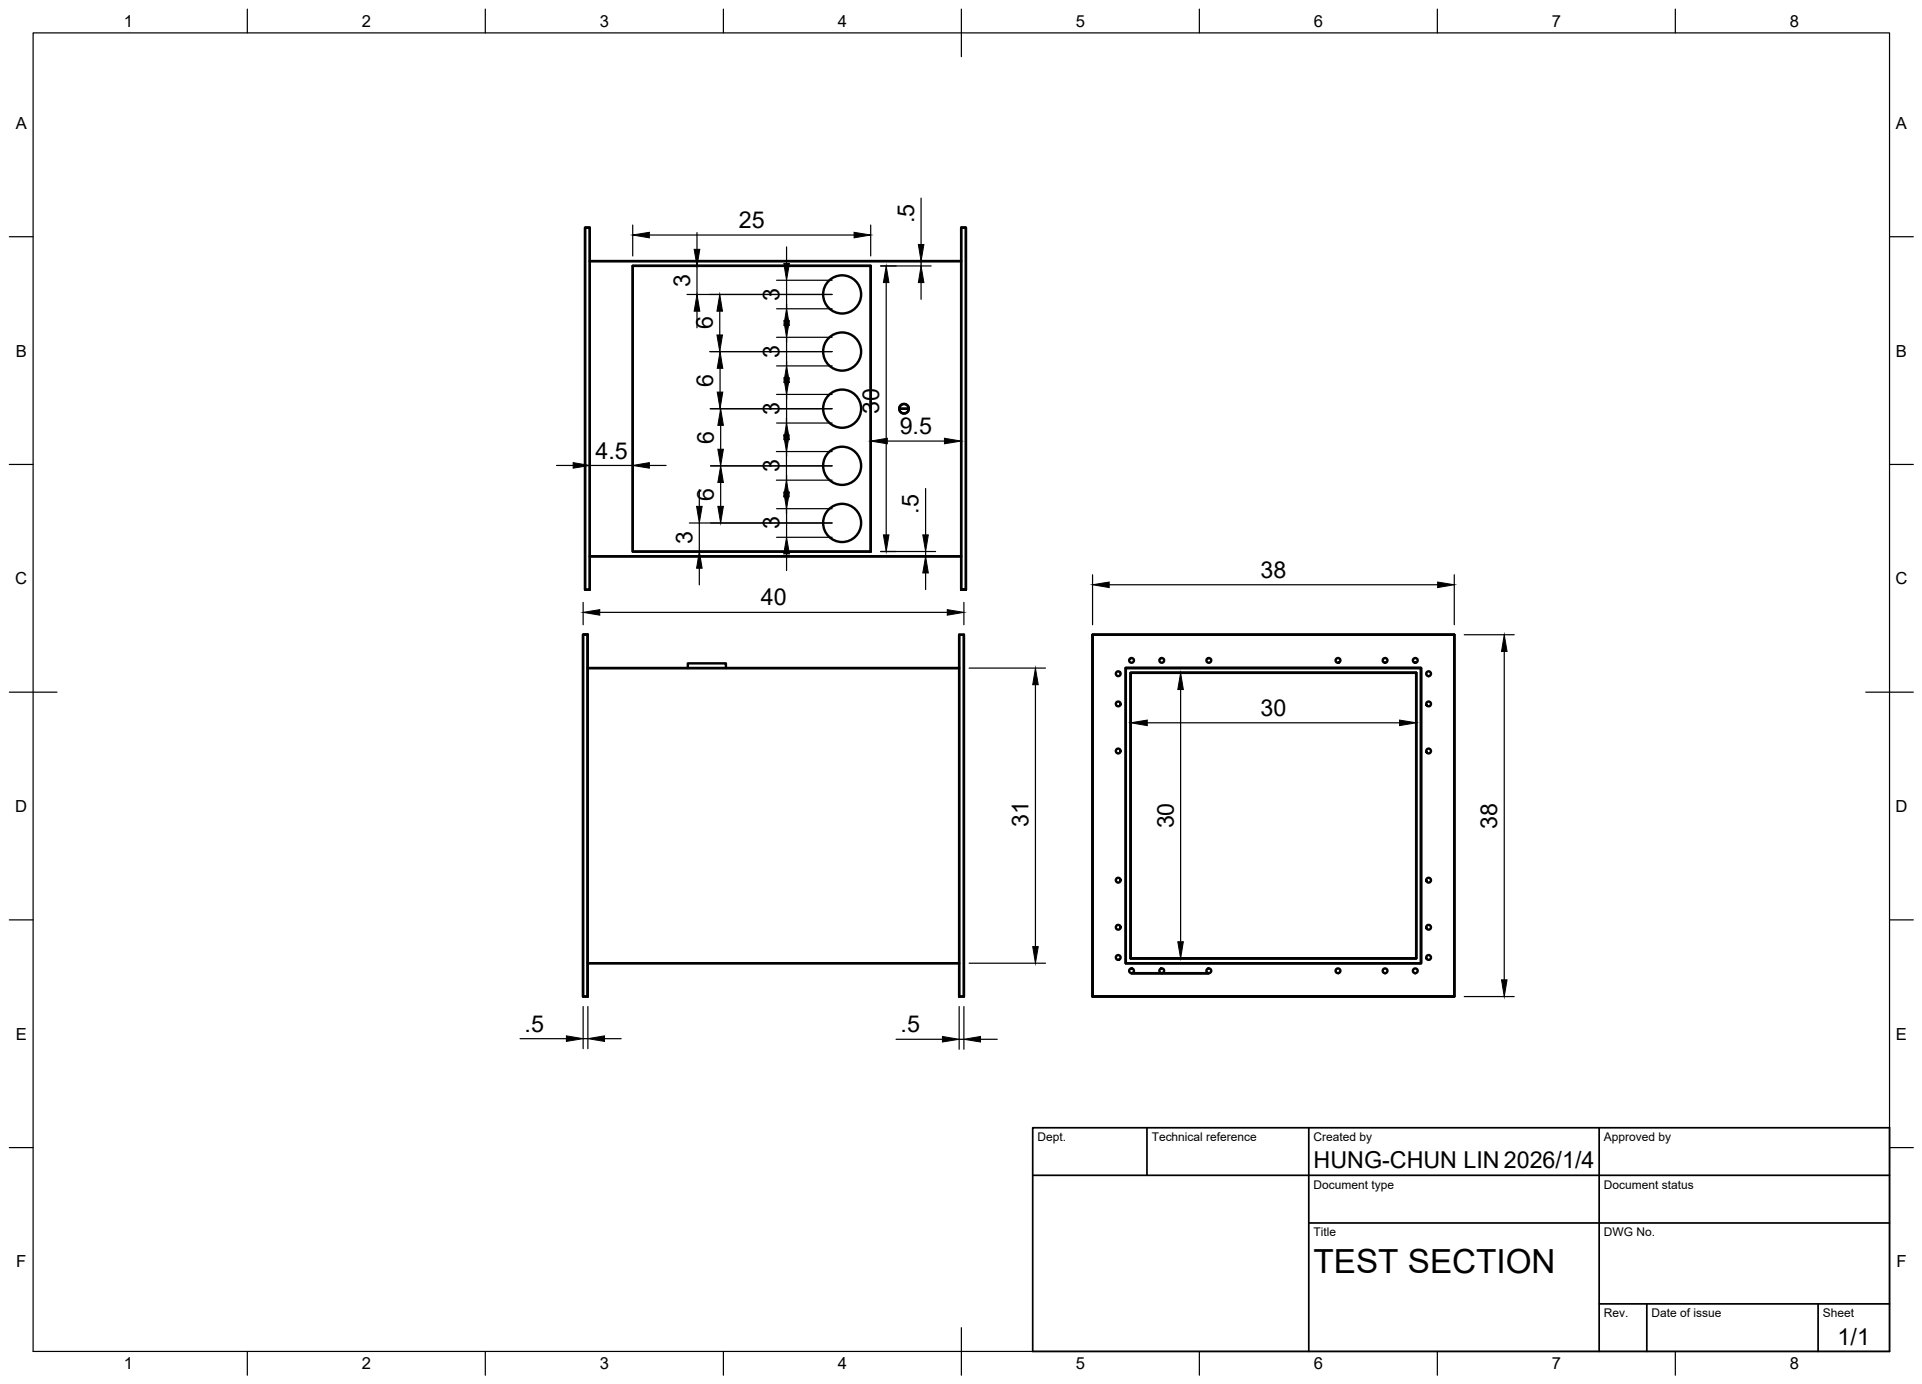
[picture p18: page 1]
Title; DWG No.; Rev.; Date of issue; Sheet; TEST SECTION

Dept. | Technical reference | Created by HUNG-CHUN LIN 2026/1/4 | Approved by

Document type | Document status

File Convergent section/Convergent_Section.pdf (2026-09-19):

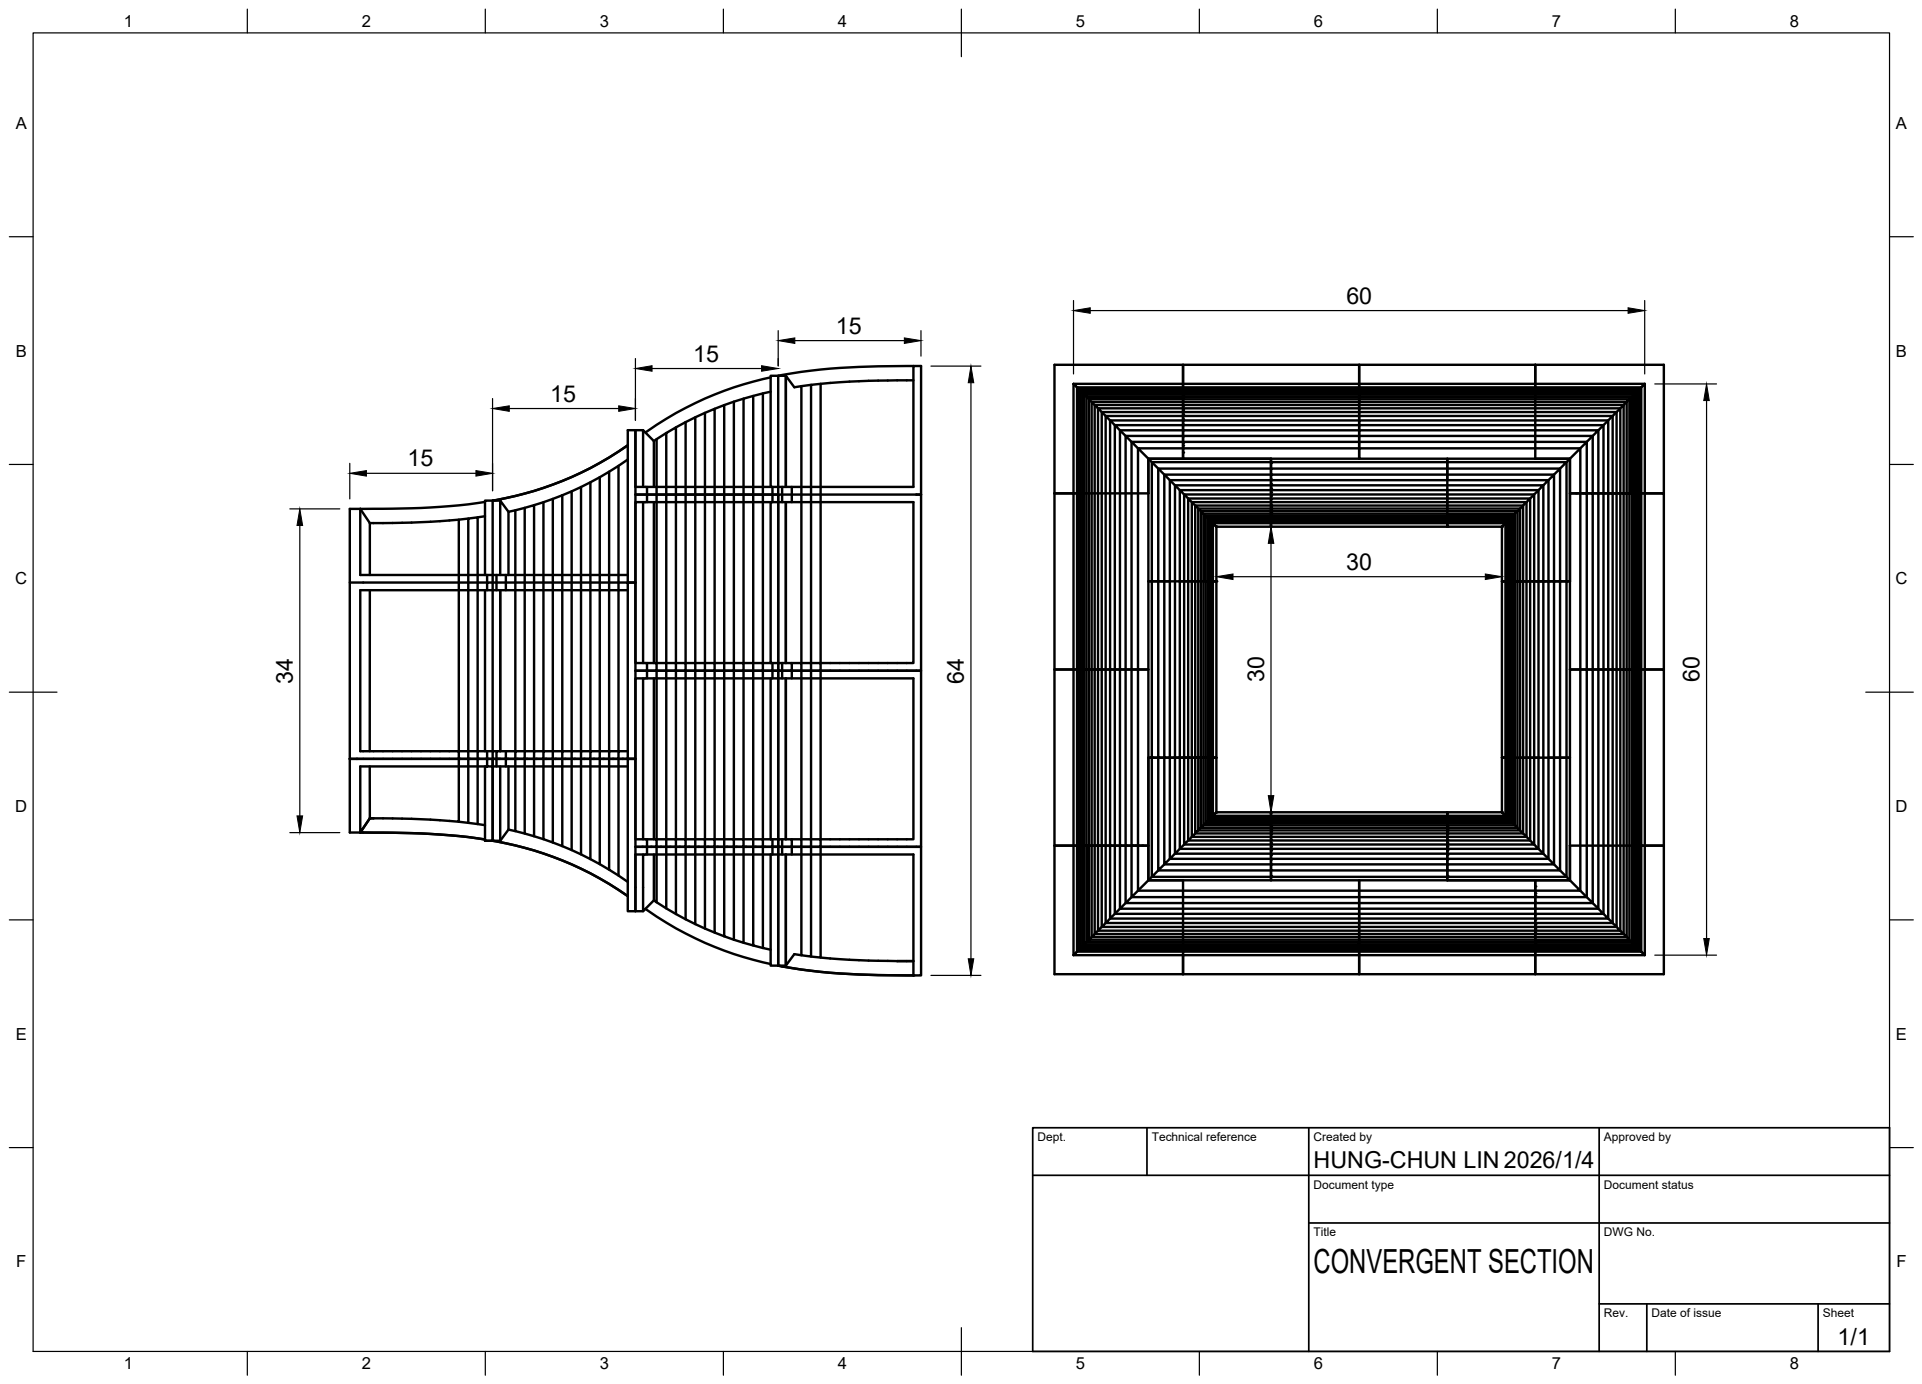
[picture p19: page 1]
Title; DWG No.; Rev.; Date of issue; Sheet; CONVERGENT SECTION

Dept. | Technical reference | Created by HUNG-CHUN LIN 2026/1/4 | Approved by

Document type | Document status

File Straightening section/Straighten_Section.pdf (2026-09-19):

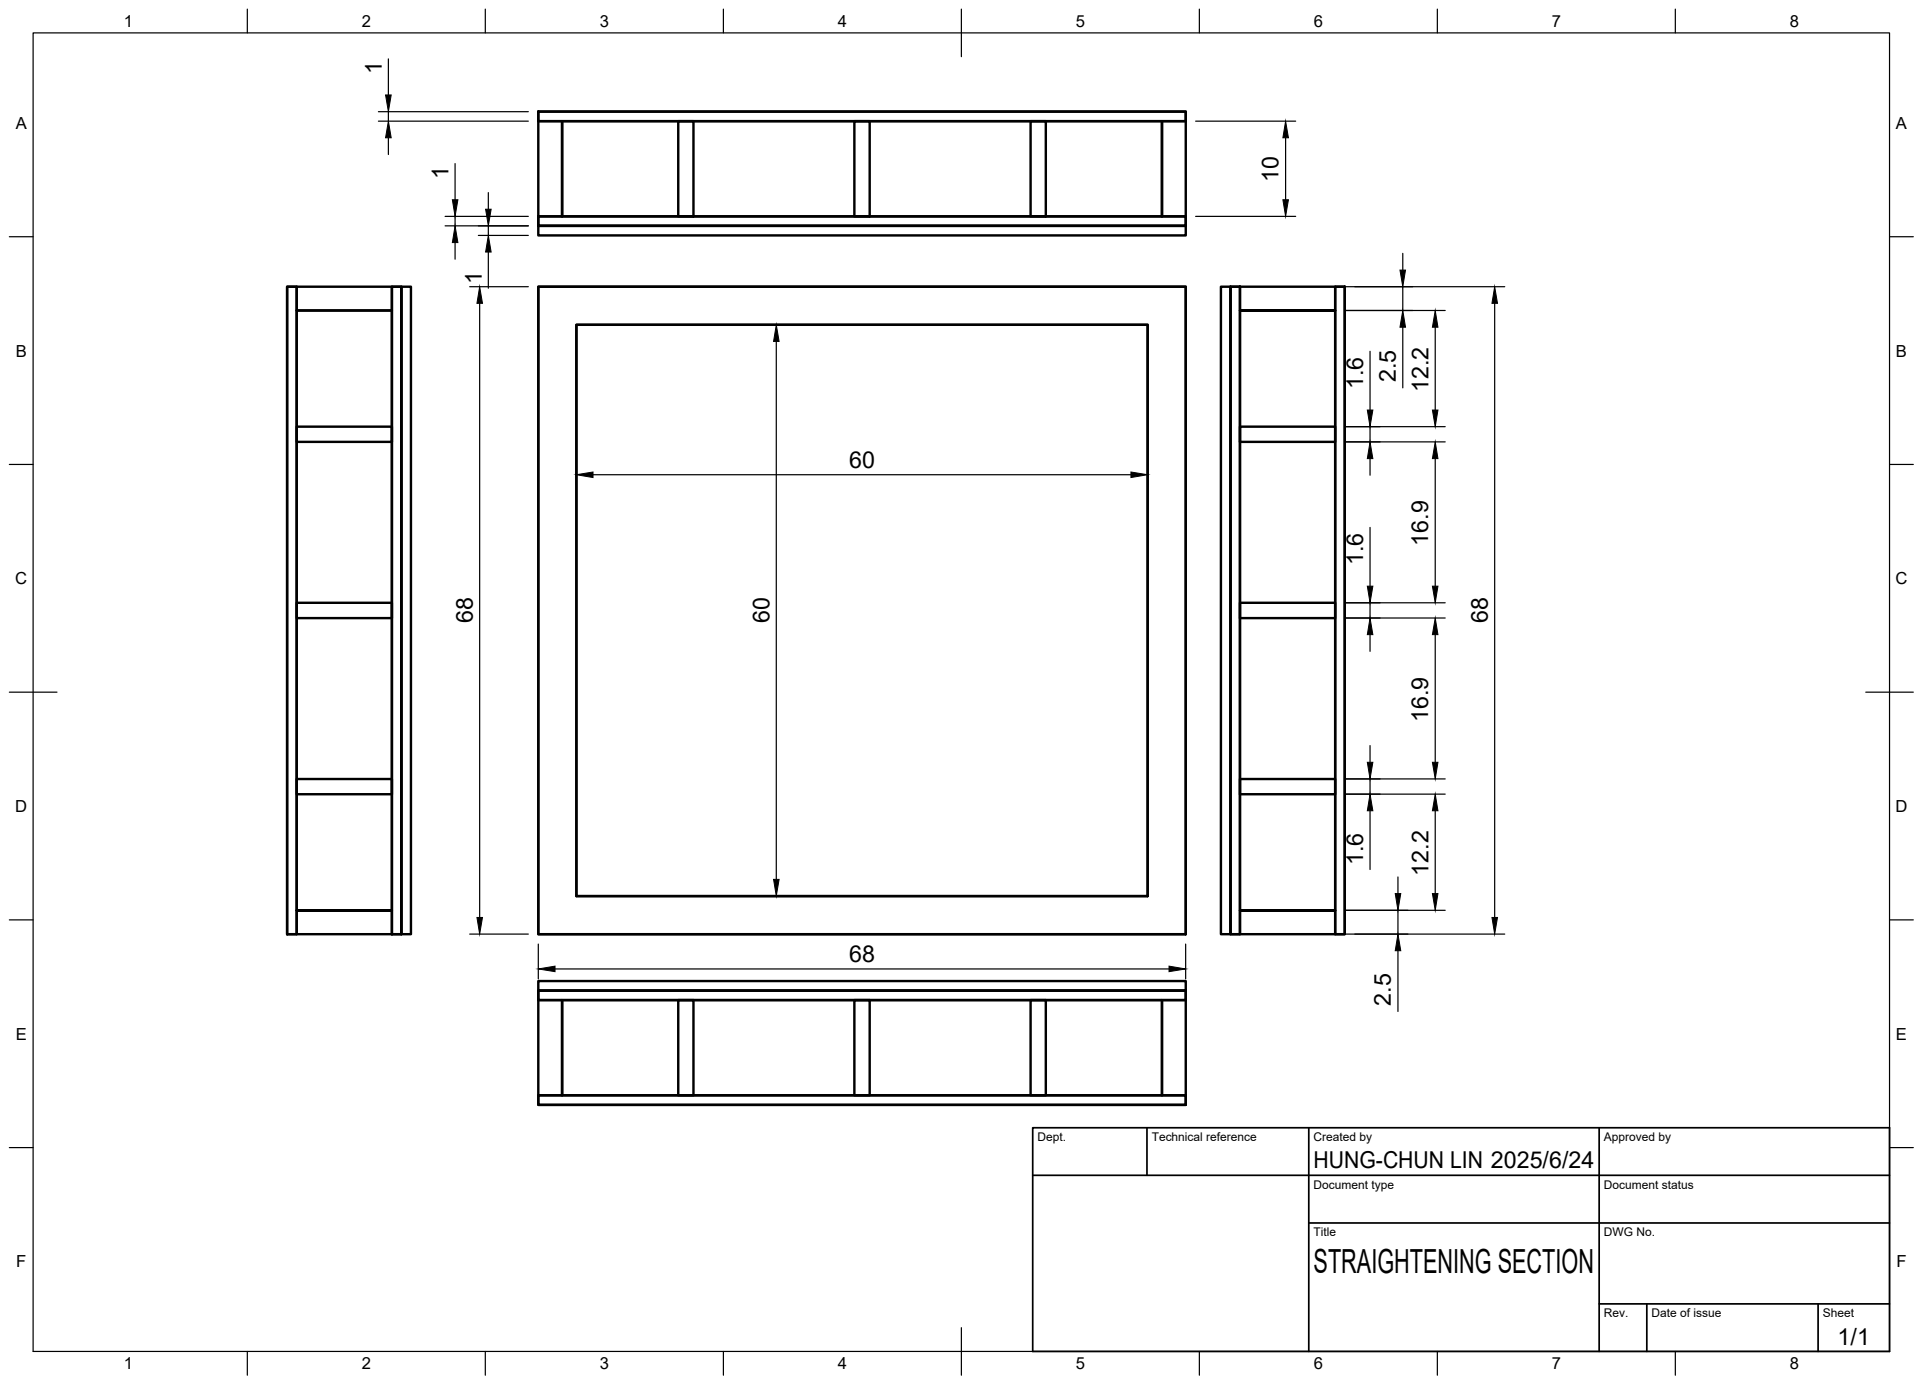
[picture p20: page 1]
Title; DWG No.; Rev.; Date of issue; Sheet; STRAIGHTENING SECTION

Dept. | Technical reference | Created by HUNG-CHUN LIN 2025/6/24 | Approved by

Document type | Document status

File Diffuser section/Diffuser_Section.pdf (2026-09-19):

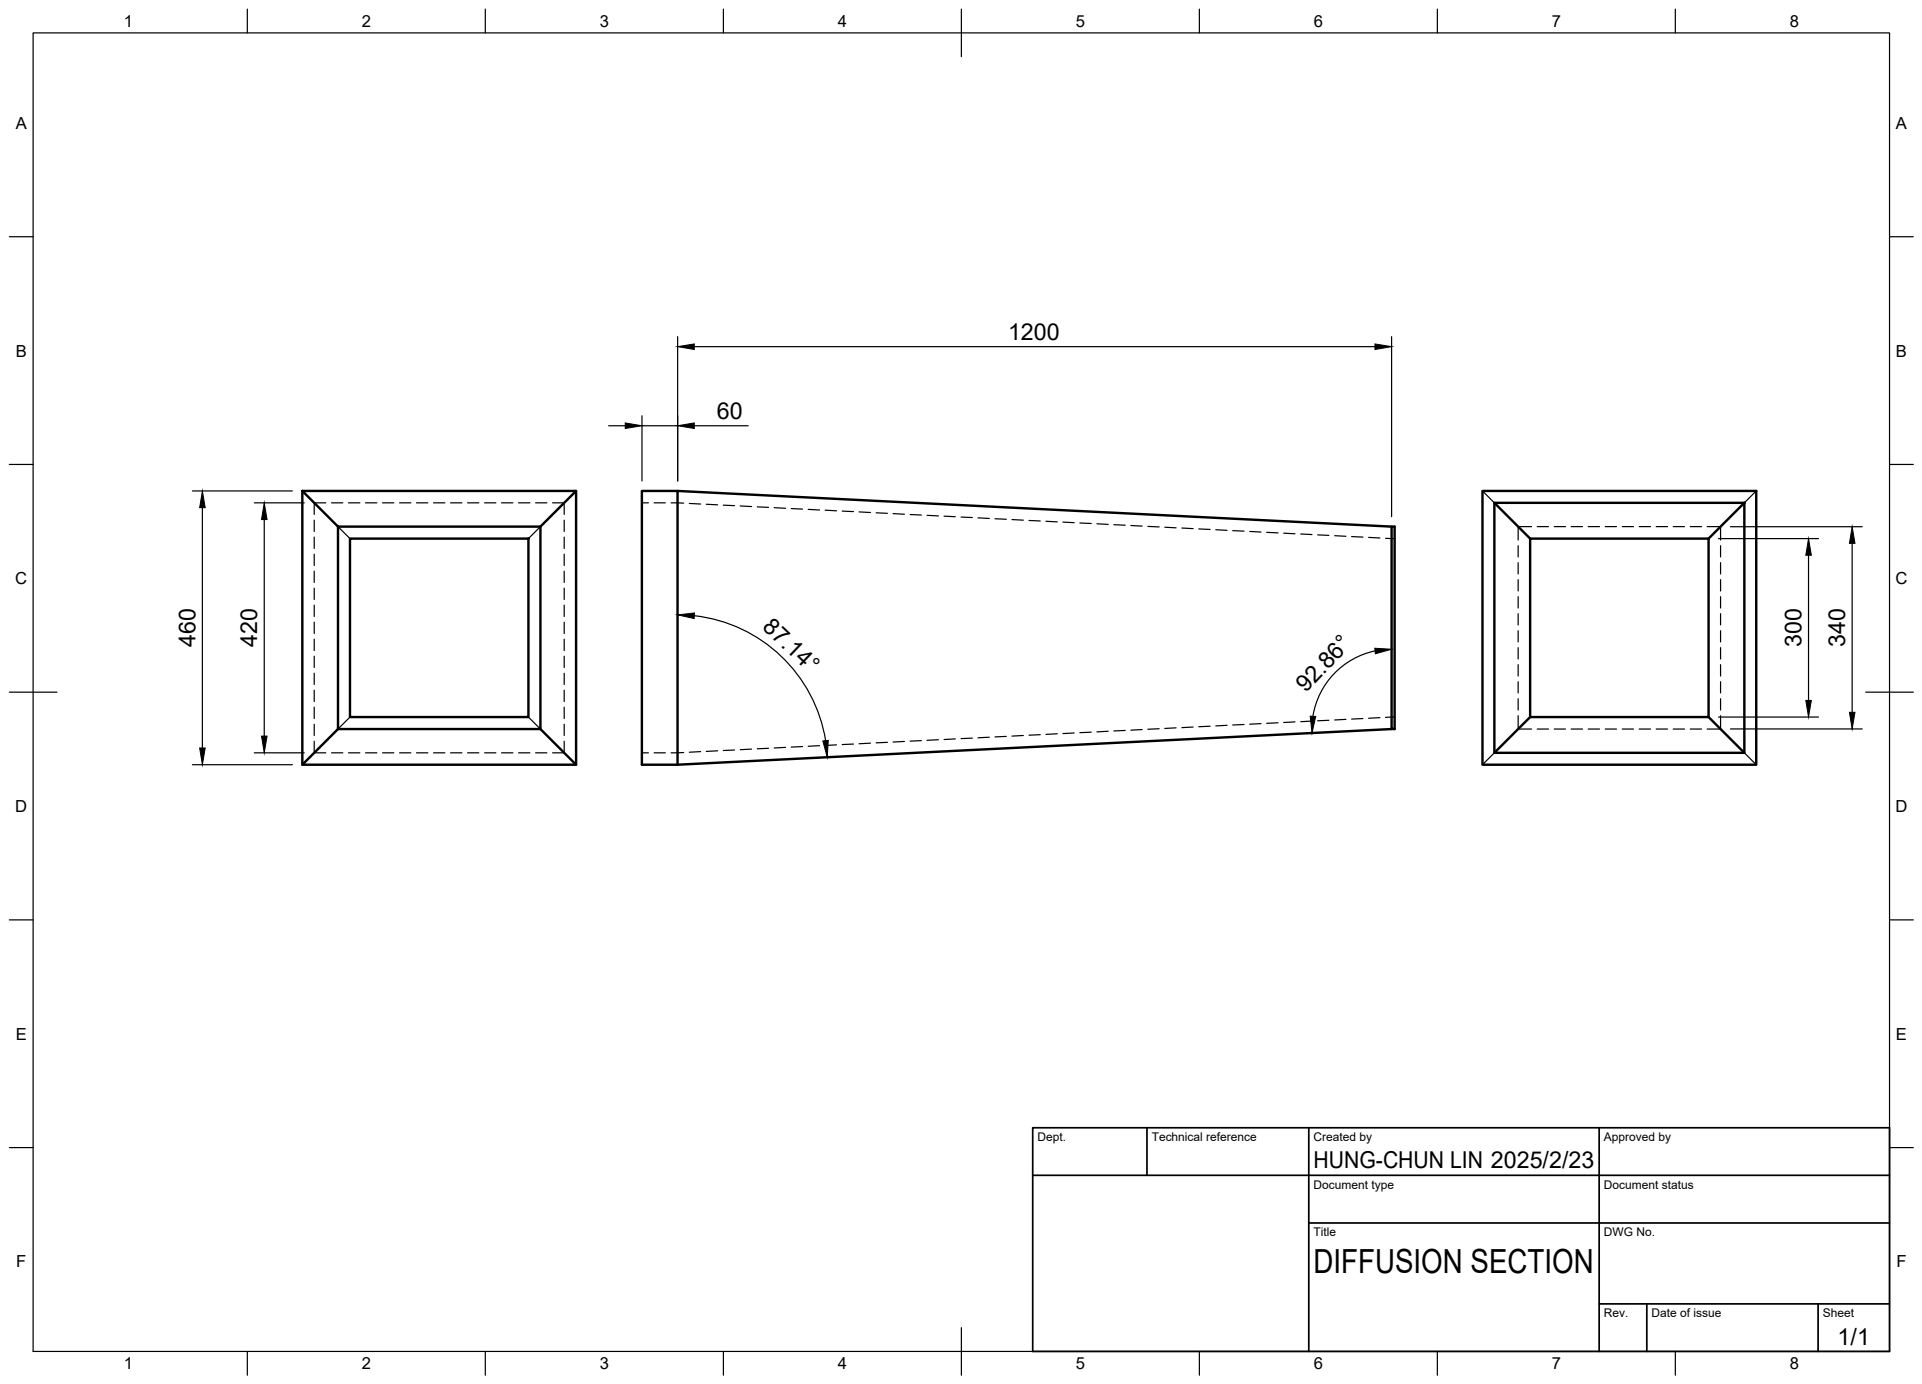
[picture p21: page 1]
Title; DWG No.; Rev.; Date of issue; Sheet; DIFFUSION SECTION; HUNG-CHUN LIN 460

Dept. | Technical reference | Created by 2025/2/23 | Approved by

Document type | Document status

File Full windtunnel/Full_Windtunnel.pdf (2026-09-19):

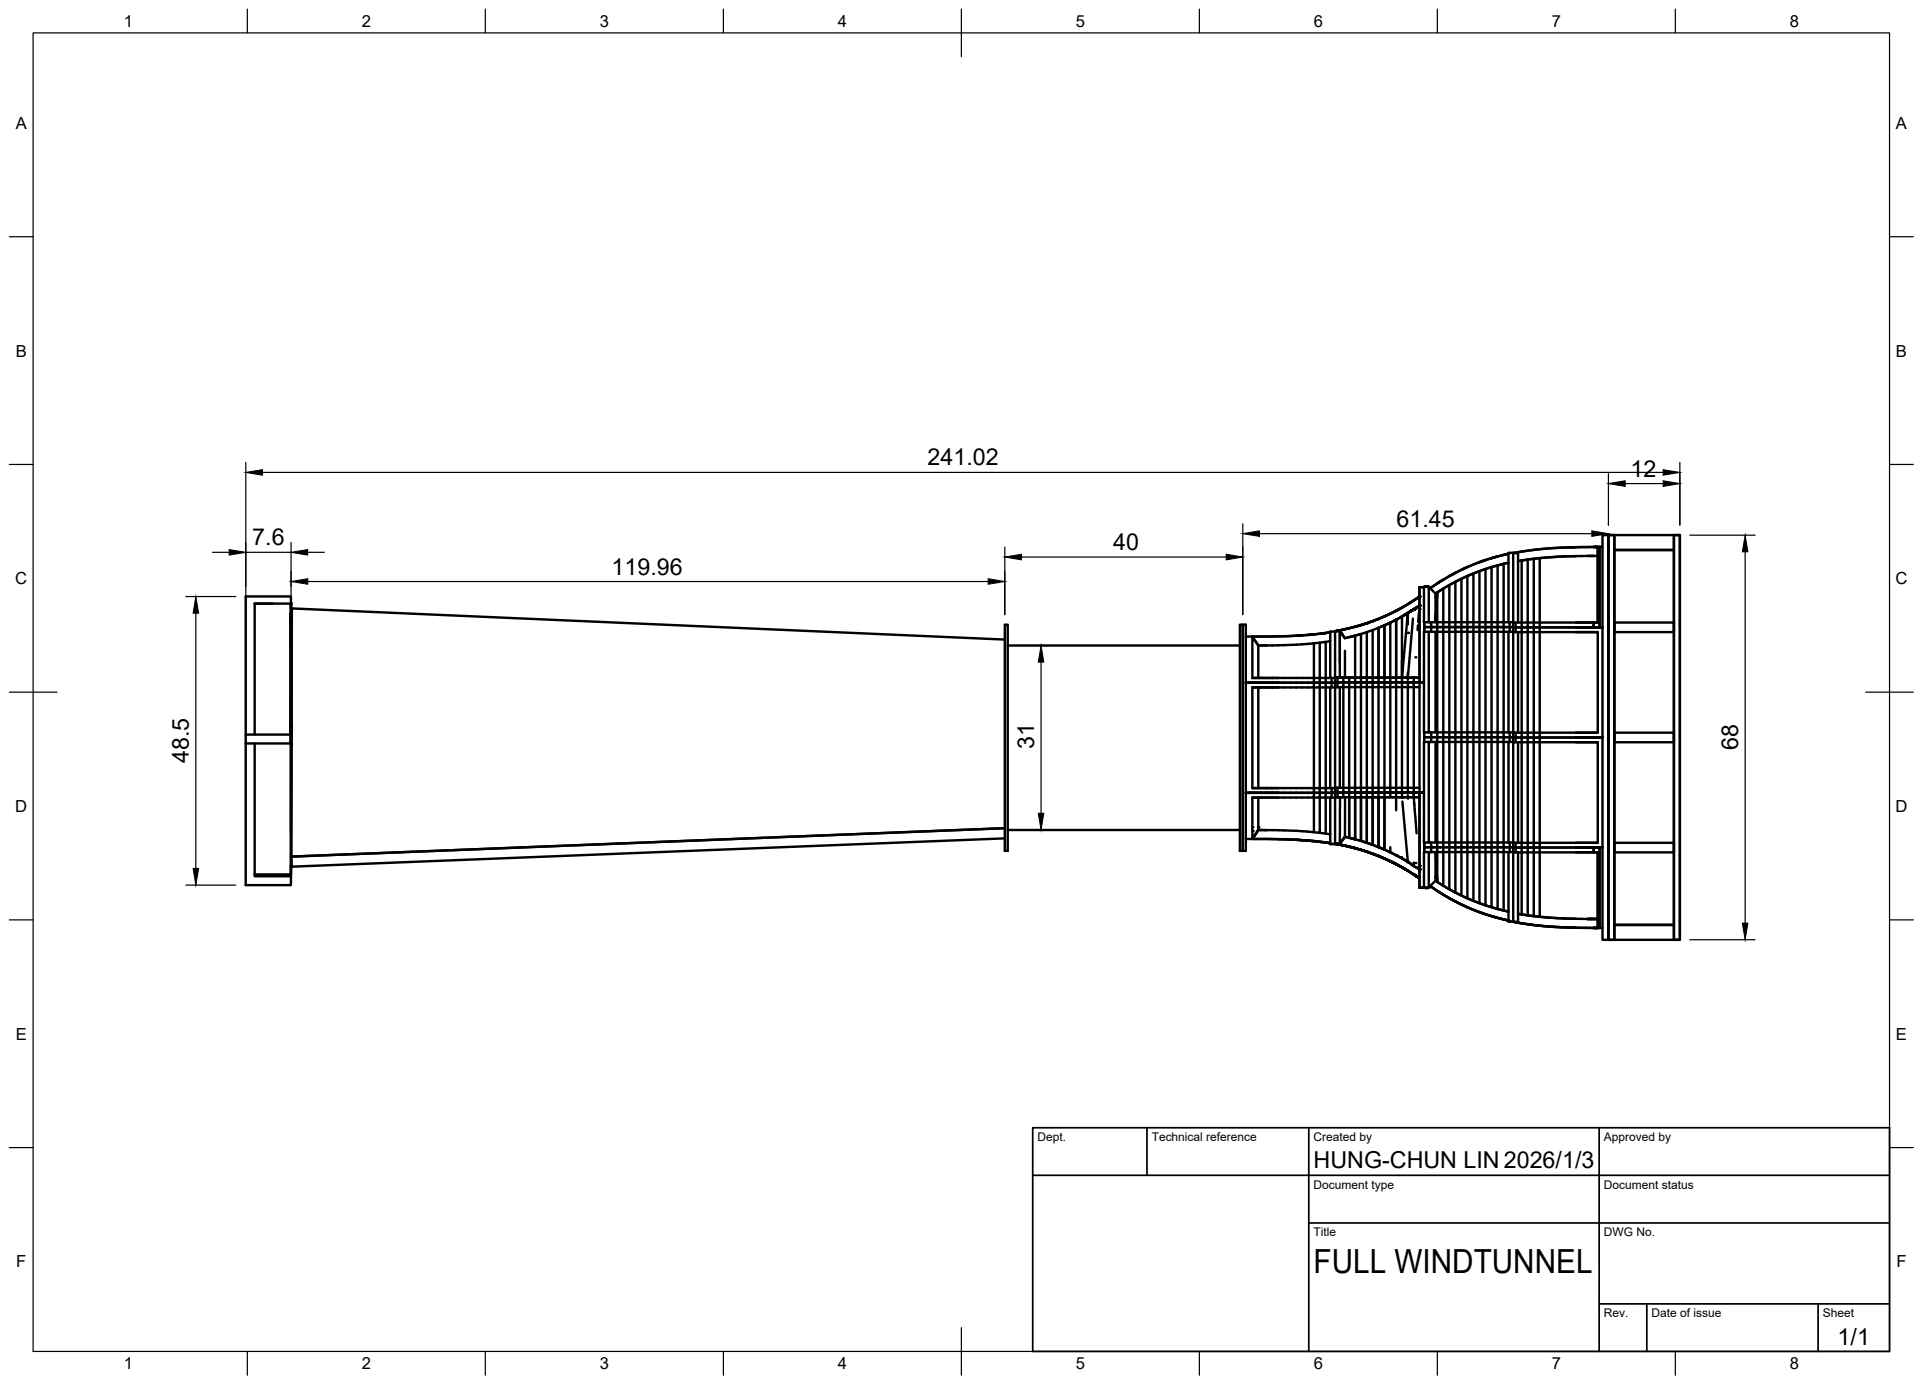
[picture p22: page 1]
Title; DWG No.; Rev.; Date of issue; Sheet; FULL WINDTUNNEL

Dept. | Technical reference | Created by HUNG-CHUN LIN 2026/1/3 | Approved by

Document type | Document status

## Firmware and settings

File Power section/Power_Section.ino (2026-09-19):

//This is the example code.
//You can modify it based on your experimental design.



//#include "arduino_secrets.h"

// Hardware Pin and Constant Definitions
#define IN 9       // Hardware PWM output pin connected to the 20x20cm fan array control line
#define MAX 255    // Maximum 8-bit PWM duty cycle value (100% duty ratio)

// ============================================================================
// ⚙️ USER CONFIGURATION: Set your test parameters here
// ============================================================================
float outputValue = 102;          // Set fan PWM output (Range: 0 - 255)
unsigned long RUN_TIME_SECONDS = 30; // Set run duration in SECONDS
// ============================================================================

int sensorPin = A0;   // Analog input pin (e.g., connected to airflow or pressure sensor)
int sensorValue = 0;  // Variable to store raw sensor readings

void setup() {  
  Serial.begin(9600);   // Initialize serial communication at 9600 bps baud rate
  pinMode(IN, OUTPUT);  // Configure Pin D9 as PWM output mode
  analogWrite(IN, 0);   // Default fan speed to 0 at power-on for system safety
}

void loop() {
  // Main control loop
  while (true) {
    sensorValue = analogRead(sensorPin);  // Read sensor voltage level from A0
    analogWrite(IN, outputValue);         // Send PWM signal to drive the fan array
    
    // Print current PWM value and calculated Duty Ratio (%) to Serial Monitor
    Serial.print("output = ");
    Serial.print(outputValue);
    Serial.print("\t Duty_Ratio = ");
    Serial.println(outputValue * 20 / 51); // Map 0-255 range to percentage: (outputValue * 100 / 255)
    
    // Maintain steady-state fan operation based on user input time (converted to ms)
    delay(RUN_TIME_SECONDS * 1000UL);  
    
    // Safety Deceleration Routine: Trigger gradual step-down if speed exceeds 80% duty ratio (> 204)
    if (outputValue > 204) {
      // Step 1: Reduce speed to PWM 160 (~63% duty ratio)
      outputValue = 160;
      analogWrite(IN, outputValue);
      delay(5000); // Hold for 5 seconds
      
      // Step 2: Reduce speed to PWM 120 (~47% duty ratio)
      outputValue = 120;
      analogWrite(IN, outputValue);
      delay(5000); // Hold for 5 seconds
      
      // Step 3: Reduce speed to PWM 80 (~31% duty ratio)
      outputValue = 80;
      analogWrite(IN, outputValue);
      delay(5000); // Hold for 5 seconds
      
      // Step 4: Reduce speed to PWM 40 (~16% duty ratio)
      outputValue = 40;
      analogWrite(IN, outputValue);
      
      // Extended idle/cooldown delay to prevent abrupt motor stoppage
      delay(60000); 
    } 
  }
}

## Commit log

2026-09-19 Modify Power & Control System section for customization
    Updated the Power & Control System section to allow for user customization.
2026-09-19 Update assembly instructions in README.md
2026-09-19 Update note on CAD model modification requirements
2026-09-19 Update damping mesh material to stainless steel
2026-09-19 Revise README with honeycomb details and construction methods
    Updated honeycomb specifications and added material guidelines for construction.
2026-09-19 Update README to clarify CAD model details
2026-09-19 Refine description of Straightening_Section.pdf
    Updated the description of the Straightening_Section.pdf to focus on the wooden frame layout.
2026-09-19 Create Power section
2026-09-19 Remove CAD directory description from README
